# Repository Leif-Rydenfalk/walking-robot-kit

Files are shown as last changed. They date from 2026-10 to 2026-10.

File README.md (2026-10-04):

# Walking robot kit: electronics and control software

Open hardware and software for a small two-legged walking robot built on the
Arduino UNO Q. Fifteen Feetech bus servos on one TTL chain, a four-layer hat
that carries the camera, the audio, the distance sensor, the inertial sensor
and the servo bus, and a daemon on the board that owns the chain and serves a
live control page at 50 Hz.

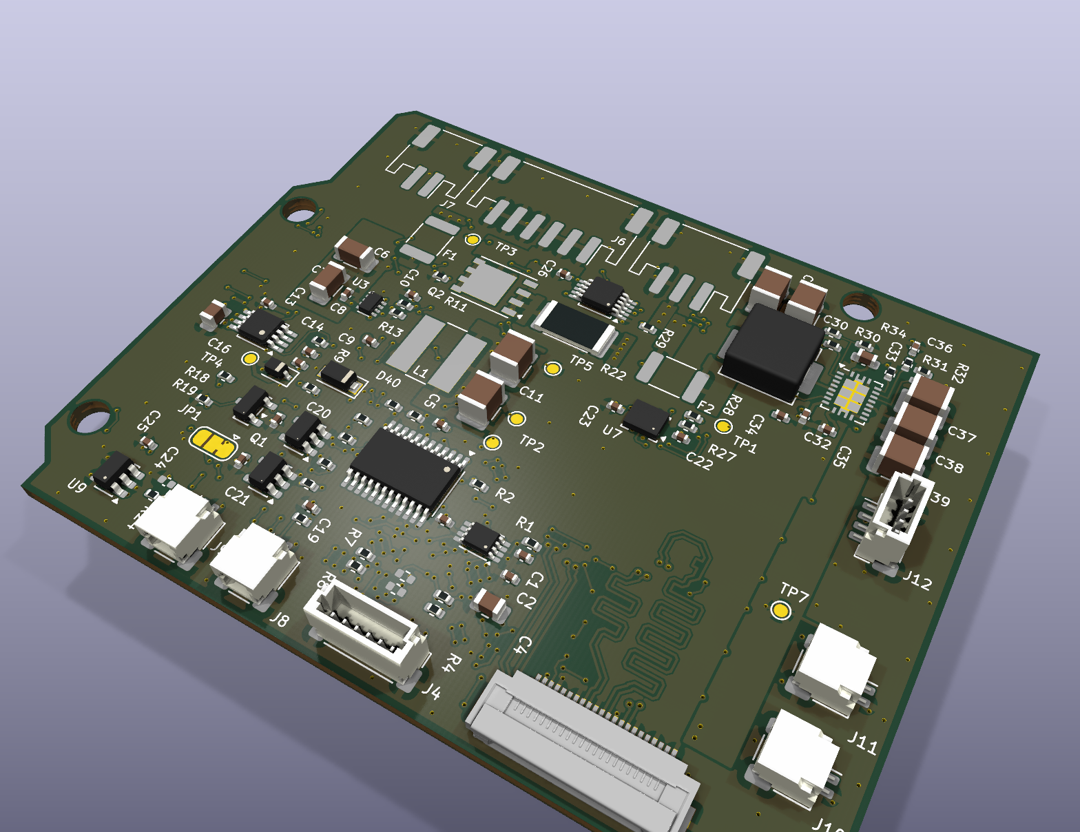
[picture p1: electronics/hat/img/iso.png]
the hat, top side


Everything here is ours and is yours to use. The printed shell is not in this
release yet; see [What is not here](#what-is-not-here).

## What is in the box

| folder | what |
|---|---|
| `electronics/hat/` | the UNO Q hat: KiCad project, schematic, gerbers, BOM and pick-and-place, plus the Python that generates all of it |
| `electronics/imu-board/` | a small breakout for the body inertial sensor |
| `firmware/bus-bridge/` | the Arduino sketch that runs the servo chain on the MCU |
| `software/servo-bus/` | the Rust daemon that owns the bus and serves the control page |
| `software/tools/` | small Python tools: check supply voltage, record joint limits, hold a pose |
| `docs/` | wiring, servo IDs, and how to bring the robot up the first time |

## What you need

- An Arduino UNO Q (ABX00162). The Linux side runs the daemon, the MCU side runs the bus.
- Fifteen Feetech STS-protocol bus servos at 1 Mbit/s. We use the HD-1910-C001.
- The hat from `electronics/hat/`, or a URT-2 adapter on D0/D1 if you only want to
  drive servos and skip the camera and audio.
- A battery between 5.0 V and 8.4 V with enough current for fifteen servos.
  Never a two-cell pack in series: 13 V burns every servo on the chain in seconds.
- A computer with Rust and either the board on your network or a USB cable.

## Build it

The hat is a four-layer board, 68.68 by 53.44 mm, ENIG. Send
`electronics/hat/fab/gerbers.zip` to any PCB maker, with `fab/bom.csv` and
`fab/cpl.csv` if you want it assembled. `electronics/hat/schematic.pdf` is the
circuit on paper. The KiCad 10 project is in `electronics/hat/kicad/` if you want
to change it, and `board.py`, `sch.py` and `hat_parts.py` are what generated it.

## Program it

Build the daemon for the board, on your computer:

    rustup target add aarch64-unknown-linux-gnu
    cargo install cargo-zigbuild                      # and install Zig
    cd software/servo-bus
    cargo zigbuild --release --target aarch64-unknown-linux-gnu

Then push the binary, the sketch and the service to the board:

    cd software
    BOARD=arduino@<board address> ./install.sh        # over the network
    ./install.sh --adb                                # or over USB

The sketch compiles and flashes on the board, which takes about a minute the
first time. Nothing moves: the daemon starts with torque untouched and only
reads the bus.

Try it without hardware first:

    cd software/servo-bus && cargo run --release -- --fake --port 8938

Then open <http://127.0.0.1:8938/>. The fake bus puts two servos on ID 1 so you
can see the duplicate-ID warning.

## Run it

Open `http://<board address>:8938/` on a phone or a computer. Every servo on the
chain shows up within two seconds: angle, load, current, temperature, supply
voltage, torque state and the angle limits it is clamped to. Add `?control` to
the URL for a position slider per servo.

Plug servos in one at a time to set their IDs. They all leave the factory at
ID 1. `docs/servos.md` has the ID map and what the page refuses to do.

`docs/running.md` is the first bring-up, in order: charge, power on, hold the
zero pose, check the inertial sensor, move one joint.

## What is not here

The printed shell. Our current parts were dimensioned from a third party's
simulation meshes, which are licensed for non-commercial use only, so we cannot
put them under an open licence. They are being redrawn from our own
measurements and will land here when that is done.

## Licence

The software, the firmware and the generator scripts are Apache-2.0
([LICENSE](LICENSE)). The board designs, the gerbers and the BOMs are
CC BY-SA 4.0 ([LICENSES/CC-BY-SA-4.0.txt](LICENSES/CC-BY-SA-4.0.txt)), because
the camera routing on the hat is copied from Arduino's own UNO Media Carrier,
which is share-alike.

Third-party work this builds on is credited in [NOTICE](NOTICE).

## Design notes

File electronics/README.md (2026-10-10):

# Electronics

Two boards. The hat is the one that matters; the IMU breakout is a small extra.

## hat

A four-layer hat for the Arduino UNO Q, 68.68 by 53.44 mm, 1.6 mm, ENIG. It
sits under the UNO Q on the two 2x30 board-to-board connectors and carries
everything the robot needs that the UNO Q does not have.

| block | part | notes |
|---|---|---|
| camera | 22-pin 0.5 mm flex connector on CSI0 | takes an IMX219 module. The ten CSI0 tracks are Arduino's own, copied from the UNO Media Carrier and length matched by them |
| power in | 6-pin JST PH pack plug (3 contacts per pole, 6 A), reverse-polarity FET, then two paths | 5.0 to 8.4 V in. Above that the daemon refuses to torque anything |
| UNO Q supply | TPS61088 boost to 11.86 V into the UNO Q's own VIN (7-24 V) | rev C. The hat never touches the UNO Q's 5 V or USB VBUS |
| amplifier supply | PTC, TPS62933 buck to 5 V | feeds only the amplifier |
| servo bus | half-duplex TTL with automatic direction | one 3-pin plug, the chain daisy-chains from there. Serial1, D0 and D1, 1 Mbit/s |
| pack monitor | INA226 across a 5 mOhm shunt in the pack feed | pack voltage and current |
| inertial | LSM6DSV16X on the 3.3 V bus at 0x6B | six axes with on-chip fusion |
| distance | header for a VL53L5CX or VL53L8CX breakout | |
| audio out | PAM8302A | one speaker plug |
| microphone | the carrier's microphone circuit | |
| touch | one capacitive pad | for petting the head |
| foot contacts | two 2-pin plugs | a switch or an FSR to ground per foot |

Everything except the board-to-board headers and the camera connector sits on
the bottom side, so nothing fouls the UNO Q above it.

### Getting one made

Send `hat/fab/gerbers.zip` to a PCB maker. Four layers, 1.6 mm, ENIG. Smallest
via is 0.20 mm drill on a 0.40 mm pad (one, inside the IMU's LGA); the rest are
0.25/0.45. For assembled boards add `fab/bom.csv`
and `fab/cpl.csv`; the part numbers are LCSC.
The order, with options, price and checks: `../docs/PCB-ORDER-LEIF-2026-10-11.md`.
Checks behind it: `hat/checks/` and `hat/docs/` (footprints, strap pins, power
budget, BOM stock).

`hat/schematic.pdf` is the circuit. `hat/kicad/` is the KiCad 10 project.

### Changing it

The board is generated, not drawn by hand. `hat_parts.py` is the whole design:
every part, every net, every position. `sch.py` turns it into the schematic and
`board.py` into the copper. Edit `hat_parts.py` and regenerate; do not edit the
KiCad files and expect the change to survive.

The CSI0 tracks are the exception. They are Arduino's, they are length matched,
and `board.py` locks them so the autorouter cannot touch them.

## imu-board

A two-layer breakout for an inertial sensor on the body plate, for when you
want the sensor away from the head. Same files, same process.

If you do not want to make a board for this, an MPU-6050 module wired straight
to the UNO Q header works. See `../docs/wiring.md`.

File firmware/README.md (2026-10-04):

# Firmware

One Arduino app, `bus-bridge`. It runs on the UNO Q's MCU and does one job:
own the servo chain on Serial1 and answer the Linux side over RouterBridge.

## What it does

- Drives the half-duplex TTL bus on D0 and D1 at 1 Mbit/s, with automatic
  direction. The hat handles the direction switch in hardware, so the sketch
  never has to toggle a transmit-enable pin.
- `bus_batch` is the fast path: one call carries a sync write of every goal
  position plus one telemetry read per servo, so a whole roster costs one
  round trip instead of fifteen.
- Sweeps the bus itself on a poll loop, so the Linux side reads a fresh
  snapshot rather than waiting for each servo in turn.
- Reads an MPU-6050 or compatible sensor over I2C, on whichever bus answers.
  It probes `Wire` (I2C2, the header pins) and `Wire1` (I2C4, the Qwiic
  socket) and reports which one replied. It does not assume.
- Drives the UNO Q's own 13 by 8 LED matrix, so the robot can show its state
  on its face.

## Flashing it

`../software/install.sh` copies this app to the board and starts it; the
sketch compiles and flashes there, which takes about a minute the first time.

By hand:

    adb push app.yaml    /home/arduino/ArduinoApps/servo-bus-mcu/app.yaml
    adb push sketch.ino  /home/arduino/ArduinoApps/servo-bus-mcu/sketch/sketch.ino
    adb push sketch.yaml /home/arduino/ArduinoApps/servo-bus-mcu/sketch/sketch.yaml
    adb push main.py     /home/arduino/ArduinoApps/servo-bus-mcu/python/main.py
    adb shell arduino-app-cli app start user:servo-bus-mcu

`main.py` is the Linux half of the app and does nothing but stay alive so the
app stays started. All the work is in `sketch.ino`.

## If the bus goes quiet

Hot-plugging a servo while the bus is running can wedge the MCU. The daemon on
the Linux side notices within a second and restarts this app, which takes about
twenty seconds, then carries on. You do not have to do anything.

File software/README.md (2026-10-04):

# Software

A Rust daemon that owns the servo bus, and a handful of Python tools that talk
to it.

## servo-bus

One process on the board's Linux side. It is the only thing allowed to touch
the bus, so nothing can fight it for the chain.

It has no dependencies. `Cargo.toml` has an empty `[dependencies]` on purpose:
the msgpack client, the HTTP server, the WebSocket and the JSON are all in
`src/`, because every one of them sits on the latency path.

### Build and install

    rustup target add aarch64-unknown-linux-gnu
    cargo install cargo-zigbuild        # and install Zig from ziglang.org
    cd servo-bus
    cargo zigbuild --release --target aarch64-unknown-linux-gnu

    cd ..
    BOARD=arduino@<board address> ./install.sh
    ./install.sh --adb                   # or over the USB cable

Then open `http://<board address>:8938/`.

### Without hardware

    cd servo-bus && cargo run --release -- --fake --port 8938

A fake bus with a few servos on it, including two sharing ID 1 so you can see
the duplicate warning. Tests run the same way: `cargo test`, no hardware.

### The page

| address | what |
|---|---|
| `/` | the roster: every servo's angle, load, current, temperature, supply voltage, torque state, limits and reply delay, updated 50 times a second. Set ID, torque off, duplicate-ID warning |
| `/?control` | the same, plus a position slider per servo |
| `/api/bus`, `/ws/bus` | the same data as JSON, polled or streamed every 20 ms |
| `/api/batch` | one call, many servos, for an outside controller |

Nothing moves unless you ask it to. The daemon starts with torque untouched,
and the page refuses to hold a servo whose ID is shared or which reads badly.

### How it keeps the servos safe

Every servo gets an angle band and goals outside it are refused, not clamped
silently. A servo with no recorded band cannot be driven at all; its slider
stays disabled. You record a band by turning the joint by hand end to end with
torque off, which the daemon watches, then saving it. The saved band is the
recorded ends minus three degrees each side, written to the servo's EEPROM and
read back.

A jaw that rests across twenty degrees and a hip that swings two hundred have
no business sharing one global limit. That is why the band is per servo.

### Speed

On an UNO Q, fifty roster updates a second. One update costs about 10.7 ms with
two servos; the link model puts sixteen servos at 16.7 ms. The limit is the
router-to-MCU link at 115200 baud, which costs about 5.5 ms per call plus 87 µs
per byte.

## tools

Small Python scripts that talk to the daemon over HTTP. No dependencies beyond
the standard library.

| tool | what |
|---|---|
| `bus_volts.py` | every servo's supply voltage and one verdict line. Safe is 5.0 to 8.4 V |
| `record_limits.py` | walk one joint end to end and save the band |
| `limits_table.py` | the bands as a table |
| `pose.py` | hold the robot in a pose by hand, record it, then have it go there by itself |
| `zero_now.py` | read the current pose and treat it as zero |
| `fte.py` | the shared client the others use: Feetech packets through the daemon's raw door |

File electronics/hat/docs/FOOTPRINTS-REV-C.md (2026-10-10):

# Rev C footprints against their datasheets

foreman/microduck-assembly.60, 2026-10-10. Generated by `tools/fp_table.py` from `data/fp-geometry.json` (pads read from the built `kicad/unoq_hat.kicad_pcb`) and `data/bom-stock.json`. Datasheets: `kit/ref/ds/<LCSC>.pdf`.

Pin 1 = pad "1" position in footprint coordinates (mm). Pitch = smallest pad centre spacing. Pin-to-net mapping is checked separately by `sch check` (74/74 nets agree between schematic and board, `checks/build-summary.json`).

| refs | LCSC | MPN | footprint | pads | pin 1 (mm) | pitch | pad w x h | datasheet vs board | verdict | datasheet |
|---|---|---|---|---|---|---|---|---|---|---|
| J1, J2 | C191721 | 1.27-2*30P | UNOQ_JMEDIA_2x30_P1.27_Male | 60 | (-18.415, -2.135) | 1.27 | 0.7x2.57 | Arduino UNO Q carrier JMEDIA/JMISC land (GPEC212-3002A011C1AF) from the Arduino carrier files: 0.7x2.57 pads, 1.27 pitch, rows 4.27 apart; 142 carrier lands matched in validation/2026-10-07-v1. Part is a BOOMELE equivalent, not the Greenconn original: first boards are the fit test | PASS, fit test | [pdf](https://datasheet.lcsc.com/datasheet/pdf/3aedae07ef21d25ca8d950ab4b2f9895.pdf?productCode=C191721) |
| R1, R2, R7, R8, R15, R16, R17, R18, R29, R25, R26 | C25744 | 0402WGF1002TCE | R_0402_1005Metric | 2 | (-0.51, 0) | 1.02 | 0.54x0.64 | IPC-7351 nominal KiCad library land; JLC basic part, same land on every 0402/0603/0805/1206/1210 the house places | PASS | [pdf](https://datasheet.lcsc.com/datasheet/pdf/0a975aaa49b7c97f38a963127be4a823.pdf?productCode=C25744) |
| R3, R4 | C17168 | 0402WGF0000TCE | R_0402_1005Metric | 2 | (-0.51, 0) | 1.02 | 0.54x0.64 | IPC-7351 nominal KiCad library land; JLC basic part, same land on every 0402/0603/0805/1206/1210 the house places | PASS | [pdf](https://datasheet.lcsc.com/datasheet/pdf/0a975aaa49b7c97f38a963127be4a823.pdf?productCode=C17168) |
| C2, C3, C5, C19, C20, C21, C13, C14, C15, C22, C23, C26, C25 | C1525 | CL05B104KO5NNNC | C_0402_1005Metric | 2 | (-0.48, 0) | 0.96 | 0.56x0.62 | IPC-7351 nominal KiCad library land; JLC basic part, same land on every 0402/0603/0805/1206/1210 the house places | PASS | [pdf](https://datasheet.lcsc.com/datasheet/pdf/02336ea48ea44ca18c72517dd3cb7b47.pdf?productCode=C1525) |
| F1 | C702820 | SMD1812P300TF/16 | Fuse_1812_4532Metric | 2 | (-2.138, 0) | 4.276 | 1.125x3.4 | 1812 PTC: Ruilon pad layout F 1.78 / G 3.45 / H 3.15. Board KiCad Fuse_1812 1.125x3.4 at +-2.138 (gap 3.15, overall 5.4): same gap, narrower pads, fine for a 4.5 mm body | PASS | [pdf](https://datasheet.lcsc.com/datasheet/pdf/cfa74b12b2251ef3c7fa909bdad1e8a9.pdf?productCode=C702820) |
| C33 | C19666 | CL10A475KO8NNNC | C_0603_1608Metric | 2 | (-0.775, 0) | 1.55 | 0.9x0.95 | IPC-7351 nominal KiCad library land; JLC basic part, same land on every 0402/0603/0805/1206/1210 the house places | PASS | [pdf](https://datasheet.lcsc.com/datasheet/pdf/02336ea48ea44ca18c72517dd3cb7b47.pdf?productCode=C19666) |
| C11, C12, C30, C31, C37, C38, C39 | C52306 | CL32A226KAJNNNE | C_1210_3225Metric | 2 | (-1.475, 0) | 2.95 | 1.15x2.7 | IPC-7351 nominal KiCad library land; JLC basic part, same land on every 0402/0603/0805/1206/1210 the house places | PASS | [pdf](https://datasheet.lcsc.com/datasheet/pdf/02336ea48ea44ca18c72517dd3cb7b47.pdf?productCode=C52306) |
| J7 | C295747 | S2B-PH-SM4-TB(LF)(SN) | JST_PH_S2B-PH-SM4-TB_1x02-1MP_P2.00mm_Horizontal | 2 | (-1, 2.85) | 2 | 1x3.5, 1.5x3.4 | JST PH S2B-PH-SM4-TB, same family as J6 | PASS | [pdf](https://datasheet.lcsc.com/datasheet/pdf/2474e9261ed7c5f86b55d373e724589d.pdf?productCode=C295747) |
| C1 | C23733 | CL05A475MP5NRNC | C_0402_1005Metric | 2 | (-0.48, 0) | 0.96 | 0.56x0.62 | IPC-7351 nominal KiCad library land; JLC basic part, same land on every 0402/0603/0805/1206/1210 the house places | PASS | [pdf](https://datasheet.lcsc.com/datasheet/pdf/02336ea48ea44ca18c72517dd3cb7b47.pdf?productCode=C23733) |
| R21, R24 | C106235 | RC0402FR-071KL | R_0402_1005Metric | 2 | (-0.51, 0) | 1.02 | 0.54x0.64 | IPC-7351 nominal KiCad library land; JLC basic part, same land on every 0402/0603/0805/1206/1210 the house places | PASS | [pdf](https://datasheet.lcsc.com/datasheet/pdf/b426be3ce22c6de3e0c3a2248e49159e.pdf?productCode=C106235) |
| C6, C7 | C77090 | GRM31CR61E106KA12L | C_1206_3216Metric | 2 | (-1.475, 0) | 2.95 | 1.15x1.8 | IPC-7351 nominal KiCad library land; JLC basic part, same land on every 0402/0603/0805/1206/1210 the house places | PASS | [pdf](https://datasheet.lcsc.com/datasheet/pdf/5d6d0805a03309170176423d23331af1.pdf?productCode=C77090) |
| L2 | C167218 | FXL0630-2R2-M | L_Changjiang_FXL0630 | 2 | (-3.025, 0) | 6.05 | 2.35x3.5 | FXL0630 land: a 3.7 gap, b 8.4 overall, c 3.5. Board 2.35x3.5 at +-3.025 (gap 3.7, overall 8.4) | PASS | [pdf](https://datasheet.lcsc.com/datasheet/pdf/40dfb6cb4606b2ccaa4e89438a42f563.pdf?productCode=C167218) |
| U7 | C5267406 | LSM6DSV16XTR | LGA-14_3x2.5mm_P0.5mm_LayoutBorder3x4y | 14 | (-1.163, 0.75) | 0.5 | 0.35x0.625, 0.625x0.35 | ST LSM6DSV16X LGA-14 2.5x3, 0.5 pitch; ST TN0018 land: pad = package pad +0.1 outward. Board 0.625x0.35 (package 0.475x0.25) | PASS | [pdf](https://datasheet.lcsc.com/datasheet/pdf/7d66556bb254f99e058243c7371e051d.pdf?productCode=C5267406) |
| U3 | C3200405 | TPS62933DRLR | SOT-583-8 | 8 | (-0.74, 0.75) | 0.5 | 0.67x0.3 | TI DRL0008A land: 0.67x0.3, 0.5 pitch, row 1.48. Board identical | PASS | [pdf](https://datasheet.lcsc.com/datasheet/pdf/8822d9443d3405e5b17304ebbb56ac2c.pdf?productCode=C3200405) |
| J3 | C3169786 | TF31-22S-0.5SH(800) | FFC_22P_P0.5_TF31-22S | 23 | (5.25, 1.625) | 0.5 | 0.3x1.3, 1.8x2.2 | TF31-22S land table: A 10.5 (21x0.5 pitch), B 12.5, C 16.3. Board: pins +-5.25 = 10.5, shield pads inner 12.5, outer 16.1 (0.1/side short). Signal 0.3x1.3 | PASS | [pdf](https://datasheet.lcsc.com/datasheet/pdf/1f4b27665a7c1a8cc6f29d17b6cec7db.pdf?productCode=C3169786) |
| J4 | C160392 | BM06B-SRSS-TB(LF)(SN) | JST_SH_BM06B-SRSS-TB_1x06-1MP_P1.00mm_Vertical | 6 | (-2.5, -1.325) | 1 | 0.6x1.55, 1.2x1.8 | JST SH BM06B-SRSS-TB: 0.6x1.55, 1.2x1.8, 1.0 pitch | PASS | [pdf](https://datasheet.lcsc.com/datasheet/pdf/e03a82bcc66e3c3589917313e54d45e2.pdf?productCode=C160392) |
| U10 | C87357 | TPS61088RHLR | Texas_VQFN-RHL-20 | 21 | (-0.75, 2.15) | 0.475 | 0.2x0.6, 0.24x0.6, 0.6x0.24 | TI RHL0020A (VQFN 3.5x4.5, 0.5 pitch, 20 pins + EP): KiCad Texas_VQFN-RHL-20 (no thermal-via variant; 4 EP vias placed by board.py in the J1 row channel). Pin map read against datasheet p3 (SW 2-4, VIN 5, PGND 11/12/20, FB 17, COMP 18, ILIM 19, FSW 3/VCC 6...) | PASS | [pdf](https://datasheet.lcsc.com/datasheet/pdf/7466a2af04454f0896e70eb827692387.pdf?productCode=C87357) |
| J8, J9, J10, J11 | C160402 | SM02B-SRSS-TB(LF)(SN) | JST_SH_SM02B-SRSS-TB_1x02-1MP_P1.00mm_Horizontal | 2 | (-0.5, 2) | 1 | 0.6x1.55, 1.2x1.8 | JST SH SM02B-SRSS-TB: 0.6x1.55, 1.2x1.8, 1.0 pitch | PASS | [pdf](https://datasheet.lcsc.com/datasheet/pdf/40c649e22fa9bda892cfec952005fd51.pdf?productCode=C160402) |
| C4, C16 | C1713 | CL21A106KOQNNNE | C_0805_2012Metric | 2 | (-0.95, 0) | 1.9 | 1x1.45 | IPC-7351 nominal KiCad library land; JLC basic part, same land on every 0402/0603/0805/1206/1210 the house places | PASS | [pdf](https://datasheet.lcsc.com/datasheet/pdf/02336ea48ea44ca18c72517dd3cb7b47.pdf?productCode=C1713) |
| C36 | C1542 | 0402B682K500NT | C_0402_1005Metric | 2 | (-0.48, 0) | 0.96 | 0.56x0.62 | IPC-7351 nominal KiCad library land; JLC basic part, same land on every 0402/0603/0805/1206/1210 the house places | PASS | [pdf](https://datasheet.lcsc.com/datasheet/pdf/09fe2daf22580a99fa7fea93ccb20fb7.pdf?productCode=C1542) |
| C8, C9, C32, C34 | C105883 | CC0402KRX7R8BB104 | C_0402_1005Metric | 2 | (-0.48, 0) | 0.96 | 0.56x0.62 | IPC-7351 nominal KiCad library land; JLC basic part, same land on every 0402/0603/0805/1206/1210 the house places | PASS | [pdf](https://datasheet.lcsc.com/datasheet/pdf/23ccee80ee542e7cf156a772bb589942.pdf?productCode=C105883) |
| R27, R28 | C25900 | 0402WGF4701TCE | R_0402_1005Metric | 2 | (-0.51, 0) | 1.02 | 0.54x0.64 | IPC-7351 nominal KiCad library land; JLC basic part, same land on every 0402/0603/0805/1206/1210 the house places | PASS | [pdf](https://datasheet.lcsc.com/datasheet/pdf/0a975aaa49b7c97f38a963127be4a823.pdf?productCode=C25900) |
| C10 | C60133 | CC0402KRX7R9BB103 | C_0402_1005Metric | 2 | (-0.48, 0) | 0.96 | 0.56x0.62 | IPC-7351 nominal KiCad library land; JLC basic part, same land on every 0402/0603/0805/1206/1210 the house places | PASS | [pdf](https://datasheet.lcsc.com/datasheet/pdf/23ccee80ee542e7cf156a772bb589942.pdf?productCode=C60133) |
| U2 | C465732 | TCA9555PWR | TSSOP-24_4.4x7.8mm_P0.65mm | 24 | (-2.862, 3.575) | 0.65 | 1.475x0.4 | TI PW0024A land: 1.5x0.45, 0.65 pitch, row 5.8. Board 1.475x0.4, span 5.724 | PASS | [pdf](https://datasheet.lcsc.com/datasheet/pdf/b87b1e8b19259fa8f353ae4a0dd9a62d.pdf?productCode=C465732) |
| D1 | C151348 | BZT52C5V1S-7-F | D_SOD-323 | 2 | (-1.05, 0) | 2.1 | 0.6x0.45 | SOD-323 land: X 0.59, X1 2.7, Y 0.45. Board 0.6x0.45 pitch 2.1 (overall 2.7) | PASS | [pdf](https://datasheet.lcsc.com/datasheet/pdf/e91584fb3d2d85e136baa2628fef5f07.pdf?productCode=C151348) |
| D40 | C426769 | BAT54H,115 | BAT54H_Nexperia_SOD123F | 2 | (-1.4, 0) | 2.8 | 1.2x1.2 | Nexperia SOD123F reflow footprint: lands 1.2 long, outer 4.0, inner 1.6, 1.1 wide. Board custom 1.2x1.2 at pitch 2.8 (outer 4.0, inner 1.6) | PASS | [pdf](https://datasheet.lcsc.com/datasheet/pdf/5d452729b69b0536541be9ab4ef736d3.pdf?productCode=C426769) |
| U1 | C840107 | TCA9406DCUR | VSSOP-8_2.3x2mm_P0.5mm | 8 | (-1.4, 0.75) | 0.5 | 1.25x0.35 | TI DCU0008A land: 0.85x0.3 pads, 0.5 pitch, row 3.1. Board 1.25x0.35, span 2.8 (KiCad VSSOP-8 2.3x2): pads reach the same toe, 0.05 wider. Pin 1 top-left | PASS | [pdf](https://www.ti.com/cn/lit/ds/symlink/tca9406.pdf) |
| U9 | C2890349 | TTP233H-BA6 | SOT-23-6 | 6 | (-1.137, 0.95) | 0.95 | 1.325x0.6 | TTP233H-BA6 SOT-23-6L: KiCad SOT-23-6 1.325x0.6, 0.95 pitch. Pin 1 = Q, 3 = I (touch), pin map in hat_parts.py | PASS | [pdf](https://datasheet.lcsc.com/datasheet/pdf/6f5612c685ffeaea62cc8564d21239f1.pdf?productCode=C2890349) |
| R32 | C26083 | 0402WGF1004TCE | R_0402_1005Metric | 2 | (-0.51, 0) | 1.02 | 0.54x0.64 | IPC-7351 nominal KiCad library land; JLC basic part, same land on every 0402/0603/0805/1206/1210 the house places | PASS | [pdf](https://datasheet.lcsc.com/datasheet/pdf/0a975aaa49b7c97f38a963127be4a823.pdf?productCode=C26083) |
| Q2 | C13899 | AON6407 | PowerPAK_SO-8_Single | 5 | (-2.67, 1.905) | 1.27 | 1.02x0.61, 1.27x0.61, 3.81x3.91 | AON6407 DFN5x6: PowerPAK SO-8 single land (pins 1-3 S, 4 G, 5-8+tab D), 1.27 pitch, 3.81x3.91 tab. Datasheet land is image-only; pinout S/S/S/G matches | PASS | [pdf](https://datasheet.lcsc.com/datasheet/pdf/0934e1c0e13d4ba28c7432f63cfc1997.pdf?productCode=C13899) |
| R11, R13, R9, R35, R36 | C25741 | 0402WGF1003TCE | R_0402_1005Metric | 2 | (-0.51, 0) | 1.02 | 0.54x0.64 | IPC-7351 nominal KiCad library land; JLC basic part, same land on every 0402/0603/0805/1206/1210 the house places | PASS | [pdf](https://datasheet.lcsc.com/datasheet/pdf/0a975aaa49b7c97f38a963127be4a823.pdf?productCode=C25741) |
| U5 | C7834 | SN74LVC1G126DBVR | SOT-23-5 | 5 | (-1.137, 0.95) | 0.95 | 1.325x0.6 | TI DBV0005A land: 1.1x0.6 pads, 0.95 pitch, row 2.6. Board SOT-23-5 1.325x0.6, span 2.275 centres. Pin 1 bottom-left | PASS | [pdf](https://datasheet.lcsc.com/datasheet/pdf/3d79861610d54464b4b035cabb370158.pdf?productCode=C7834) |
| R33 | C25746 | 0402WGF1133TCE | R_0402_1005Metric | 2 | (-0.51, 0) | 1.02 | 0.54x0.64 | IPC-7351 nominal KiCad library land; JLC basic part, same land on every 0402/0603/0805/1206/1210 the house places | PASS | [pdf](https://datasheet.lcsc.com/datasheet/pdf/0a975aaa49b7c97f38a963127be4a823.pdf?productCode=C25746) |
| J6 | C265405 | S6B-PH-SM4-TB(LF)(SN) | JST_PH_S6B-PH-SM4-TB_1x06-1MP_P2.00mm_Horizontal | 6 | (-5, 2.85) | 2 | 1x3.5, 1.5x3.4 | JST PH S6B-PH-SM4-TB (pack in, 3 contacts per pole): 1.0x3.5 signal, 1.5x3.4 mount, 2.0 pitch, pins +-5.0, mount pads +-7.35 (JST drawing; KiCad footprint drawn from it) | PASS | [pdf](https://datasheet.lcsc.com/datasheet/pdf/fd6b0599884a99953f02d32fdcec9311.pdf?productCode=C265405) |
| U8 | C49851 | INA226AIDGSR | TSSOP-10_3x3mm_P0.5mm | 10 | (-2.15, 1) | 0.5 | 1.45x0.3 | TI DGS0010A land: 1.45x0.3, 0.5 pitch, row 4.4. Board 1.45x0.3, span 4.3 | PASS | [pdf](https://datasheet.lcsc.com/datasheet/pdf/c67b965eb2a01e8d671b6f15d639e314.pdf?productCode=C49851) |
| J12 | C160390 | BM04B-SRSS-TB(LF)(SN) | JST_SH_BM04B-SRSS-TB_1x04-1MP_P1.00mm_Vertical | 4 | (-1.5, -1.325) | 1 | 0.6x1.55, 1.2x1.8 | JST SH BM04B-SRSS-TB: 0.6x1.55 signal, 1.2x1.8 mount, 1.0 pitch | PASS | [pdf](https://datasheet.lcsc.com/datasheet/pdf/00659630c8ad1e2184fc3218d8262faf.pdf?productCode=C160390) |
| F2 | C2844238 | JK-MSMD500L-12V | Fuse_1812_4532Metric | 2 | (-2.138, 0) | 4.276 | 1.125x3.4 | JK-MSMD500L 1812 PTC: same 1812 body (4.37-4.73 x 3.07-3.41) as F1; same land | PASS | [pdf](https://datasheet.lcsc.com/datasheet/pdf/4b6c851584ad23fd00938c1a71f72301.pdf?productCode=C2844238) |
| R14 | C25879 | 0402WGF2201TCE | R_0402_1005Metric | 2 | (-0.51, 0) | 1.02 | 0.54x0.64 | IPC-7351 nominal KiCad library land; JLC basic part, same land on every 0402/0603/0805/1206/1210 the house places | PASS | [pdf](https://datasheet.lcsc.com/datasheet/pdf/0a975aaa49b7c97f38a963127be4a823.pdf?productCode=C25879) |
| R22 | C185817 | RLM25FEER005 | R_2512_6332Metric | 2 | (-2.962, 0) | 5.924 | 1.225x3.35 | RLM25 2512 shunt land: a 4.0, b 2.1, L 4.1 for 0.004-0.050 ohm. Board KiCad R_2512 1.225x3.35 at pitch 5.924. Kelvin taps in board.py | PASS | [pdf](https://datasheet.lcsc.com/datasheet/pdf/f42cc89de166d1a84d9a917c44512826.pdf?productCode=C185817) |
| Q1 | C727128 | MMBT3906 | SOT-23 | 3 | (-0.938, 0.95) | 1.9 | 1.475x0.6 | SOT-23 (TO-236AB): KiCad SOT-23 1.475x0.6, pins 1/2 west, 3 east | PASS | [pdf](https://datasheet.lcsc.com/datasheet/pdf/5fb8abfb58de49a9e93c5a14c4951afe.pdf?productCode=C727128) |
| R19 | C25765 | 0402WGF2002TCE | R_0402_1005Metric | 2 | (-0.51, 0) | 1.02 | 0.54x0.64 | IPC-7351 nominal KiCad library land; JLC basic part, same land on every 0402/0603/0805/1206/1210 the house places | PASS | [pdf](https://datasheet.lcsc.com/datasheet/pdf/0a975aaa49b7c97f38a963127be4a823.pdf?productCode=C25765) |
| R30 | C25774 | 0402WGF3003TCE | R_0402_1005Metric | 2 | (-0.51, 0) | 1.02 | 0.54x0.64 | IPC-7351 nominal KiCad library land; JLC basic part, same land on every 0402/0603/0805/1206/1210 the house places | PASS | [pdf](https://datasheet.lcsc.com/datasheet/pdf/0a975aaa49b7c97f38a963127be4a823.pdf?productCode=C25774) |
| R31 | C25755 | 0402WGF1503TCE | R_0402_1005Metric | 2 | (-0.51, 0) | 1.02 | 0.54x0.64 | IPC-7351 nominal KiCad library land; JLC basic part, same land on every 0402/0603/0805/1206/1210 the house places | PASS | [pdf](https://datasheet.lcsc.com/datasheet/pdf/0a975aaa49b7c97f38a963127be4a823.pdf?productCode=C25755) |
| R12 | C27011 | 0402WGF5233TCE | R_0402_1005Metric | 2 | (-0.51, 0) | 1.02 | 0.54x0.64 | IPC-7351 nominal KiCad library land; JLC basic part, same land on every 0402/0603/0805/1206/1210 the house places | PASS | [pdf](https://datasheet.lcsc.com/datasheet/pdf/0a975aaa49b7c97f38a963127be4a823.pdf?productCode=C27011) |
| U4 | C113367 | PAM8302AASCR | MSOP-8_3x3mm_P0.65mm | 8 | (-2.112, 0.975) | 0.65 | 1.625x0.4 | PAM8302 MSOP-8: C 0.65, X 0.45, Y 1.35, Y1 5.3. Board 1.625x0.4, span 4.224 (toe 5.85): longer, 0.05 narrower | PASS | [pdf](https://datasheet.lcsc.com/datasheet/pdf/f2301bec36461d1ce751d45a4a680a5d.pdf?productCode=C113367) |
| U6 | C23654 | SN74LVC1G125DBVR | SOT-23-5 | 5 | (-1.137, 0.95) | 0.95 | 1.325x0.6 | Same DBV0005A as U5 | PASS | [pdf](https://datasheet.lcsc.com/datasheet/pdf/397db609d8c243daaad8f1a233af4e5d.pdf?productCode=C23654) |
| L1 | C168072 | FNR6045S6R8MT | FNR6045_6.0x6.0mm | 2 | (-2.15, 0) | 4.3 | 2.1x6.2 | FNR6045 6x6 shielded inductor: land carried from Rev B validation (2.1x6.2 at +-2.15); datasheet text is image-only | PASS (Rev B land) | [pdf](https://datasheet.lcsc.com/datasheet/pdf/a0b12ba9dfe6b9e66b6bb852b7c71c03.pdf?productCode=C168072) |
| J5 | C265101 | S3B-PH-SM4-TB(LF)(SN) | JST_PH_S3B-PH-SM4-TB_1x03-1MP_P2.00mm_Horizontal | 3 | (-2, 2.85) | 2 | 1x3.5, 1.5x3.4 | JST PH S3B-PH-SM4-TB, same family as J6 | PASS | [pdf](https://datasheet.lcsc.com/datasheet/pdf/6c6fce4367275d84ec6a99bf09f1250f.pdf?productCode=C265101) |
| R34 | C25762 | 0402WGF1802TCE | R_0402_1005Metric | 2 | (-0.51, 0) | 1.02 | 0.54x0.64 | IPC-7351 nominal KiCad library land; JLC basic part, same land on every 0402/0603/0805/1206/1210 the house places | PASS | [pdf](https://datasheet.lcsc.com/datasheet/pdf/0a975aaa49b7c97f38a963127be4a823.pdf?productCode=C25762) |
| C35 | C82219 | 0402B473K500NT | C_0402_1005Metric | 2 | (-0.48, 0) | 0.96 | 0.56x0.62 | IPC-7351 nominal KiCad library land; JLC basic part, same land on every 0402/0603/0805/1206/1210 the house places | PASS | [pdf](https://datasheet.lcsc.com/datasheet/pdf/09fe2daf22580a99fa7fea93ccb20fb7.pdf?productCode=C82219) |
| R20 | C138002 | RC0402FR-0733RL | R_0402_1005Metric | 2 | (-0.51, 0) | 1.02 | 0.54x0.64 | IPC-7351 nominal KiCad library land; JLC basic part, same land on every 0402/0603/0805/1206/1210 the house places | PASS | [pdf](https://datasheet.lcsc.com/datasheet/pdf/b426be3ce22c6de3e0c3a2248e49159e.pdf?productCode=C138002) |

51 footprints, 0 not PASS.

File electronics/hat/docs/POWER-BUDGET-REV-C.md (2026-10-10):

# Rev C power budget

foreman/microduck-assembly.60, 2026-10-10. Every rail on the UNO Q head hat, its
source, its limit, the worst load we can name, and the margin. Margin = 1 - load/limit.

## 1. The power tree

```
2S pack 5.0-8.4 V ── J6 (JST PH 6-pin, 3 contacts per pole) ── Q2 AON6407 reverse-polarity P-FET
   └─ R22 5 mOhm shunt (INA226 U8 reads V and I) ── VBAT
        ├─ F2 5 A PTC ── U10 TPS61088 boost ── VIN12 11.86 V ── J1.57 + J1.59 ── UNO Q VIN
        │                                                         (UNO Q makes its own 5 V, 3.3 V, 1.8 V)
        ├─ F1 3 A PTC ── U3 TPS62933 buck ── V5 5.0 V ── U4 PAM8302 amplifier only
        └─ J5.2 servo-bus VBAT reference (see section 4)
UNO Q +3V3 (J1.58/60, J2.53/55) and +1V8 (J2.57) ── hat logic, camera, ToF, IMU
```

Rev C change: the hat no longer back-feeds the UNO Q's 5 V (JMISC 54/56 are open). The
UNO Q runs from its own VIN, fed by the boost. V5 now feeds only the amplifier.

## 2. Loads

| load | rail | worst current | source of the number |
|---|---|---|---|
| UNO Q, whole board | VIN12 | 15 W on 5V_SYS (3 A) | ABX00162 datasheet sec. 3.1, 5V_SYS max |
| UNO Q VIN path | VIN12 | 15 W / 0.90 buck + Schottky 0.39 V drop = 18.1 W = 1.52 A at 11.86 V | UNO Q schematic: VIN buck then Schottky; 90 % buck assumed |
| camera module (IMX219 class) | UNO Q +3V3 / +1V8 | 250 mA | `board.py` RAIL netclass note |
| VL53L5CX ToF (J4) | +3V3 | 100 mA | same |
| LSM6DSV16X, TCA9555, INA226, TCA9406, TTP233H, buffers | +3V3 | < 10 mA together | datasheets (each under 1 mA active) |
| PAM8302 at 2.5 W into 4 ohm | V5 | 0.65 A peak | PAM8302 datasheet, 2.5 W at 5 V |
| U10 EN divider R35+R36 | VBAT_B | 42 uA at 8.4 V | Ohm's law |

The hat's 3.3 V and 1.8 V loads come out of the UNO Q's own regulators, so they are
inside the UNO Q's 15 W above and do not add to the hat converters.

## 3. Margin per rail

| rail / part | limit | worst load | margin | notes |
|---|---|---|---|---|
| VIN12 boost output (U10) | 2.03 A at 5.0 V in | 1.52 A | **25 %** | limit from ILIM min 7.1 A (R31 150k), ripple 3.4 A p-p with L -20 %, 90 % efficiency. At 6.0 V pack the limit is 2.43 A (37 %) |
| L2 FXL0630-2R2 | Isat 10.5 A | 5.4 A peak | **49 %** | peak = average input 4.0 A + half ripple 1.4 A (nominal L) |
| L2 inside current limit | ILIM min 7.1 A | 5.4 A peak | **24 %** | the boost limits before L2 saturates |
| F2 JK-MSMD500L (VBAT_B) | 5.0 A hold at 25 C | 4.0 A at 5.0 V pack | **20 %** | at 6.0 V pack 3.34 A (33 %). PTC hold falls about 20 % at 50 C: at a hot, empty pack the margin is near zero, see 5.1 |
| JMEDIA J1.57 + J1.59 (UNO Q VIN) | 1.0 A per contact | 0.76 A each | **24 %** | two contacts share 1.52 A |
| U10 junction | 125 C | 102 C at 40 C ambient | **18 %** | about 1.6 W in the IC (2.0 W total loss at 90 %, 0.24 W of it in L2) at worst load x RthJA 38.8 C/W |
| V5 buck (U3 TPS62933) | 3 A | 0.65 A | **78 %** | amplifier only after Rev C |
| F1 SMD1812P300TF (VBAT_F) | 3.0 A hold | 0.72 A at 5.0 V pack | **76 %** | |
| L1 FNR6045 6.8 uH | 3.3 A | 0.65 A + ripple | **> 70 %** | |
| R22 shunt 2 W | 2 W | 4.7 A: 0.11 W | **95 %** | INA226 range +-81.92 mV = +-16 A |
| Q2 AON6407 | 85 A class, < 6 mOhm | 4.7 A: 0.13 W | **> 90 %** | |
| J6 pack connector S6B-PH-SM4-TB, 3 contacts per pole | 6 A (2 A per JST PH contact) | 4.72 A at 5.0 V with UNO Q at 15 W and amp at full | **21 %** | realistic load 2.76 A (54 %). Was 2 per pole (4 A, -18 %) until build #10 |
| UNO Q +3V3 to hat | UNO Q regulator (inside 15 W) | 360 mA | - | the hat adds no regulator here |

## 4. Servo power

Servo power does not come from this board (`docs/wiring.md`: give the chain its own
5.0-8.4 V supply and share ground). J5 pin 2 carries VBAT only as a reference for a
servo bus that is powered elsewhere. A JST PH contact is rated 2 A; do not run servo
current through J5.

## 5. Corners to know

### 5.1 Hot, empty pack

At 5.0 V in, 50 C board and the UNO Q at its 15 W maximum, F2's hold current (about 4 A
derated) meets the 4.0 A draw. The UNO Q never draws 15 W from 5V_SYS in this robot:
that figure includes the USB-C host port at 3 A. A realistic heavy load (NPU plus camera
streaming, 8 W) needs 2.04 A from the pack at 5.0 V, 49 % under F2's derated hold.

### 5.2 J6 pack connector

Up to build #9 J6 was a 4-pin PH with two contacts per pole: 4 A, below the 4.72 A worst
case (UNO Q at 15 W plus the amplifier at full, 5.0 V pack). A kit buyer plugs in whatever
they have, so build #10 (2026-10-10) made J6 a 6-pin S6B-PH-SM4-TB (C265405) with three
contacts per pole: 6 A, 21 % over the worst case. The kit ships a J6-to-XT30 pigtail so the
buyer plugs in a normal 2S pack (see the order sheet).

## 6. Method

- Boost limit: D = 1 - VIN x eta / VOUT; ripple = VIN x D / (L x fSW); average input
  limit = ILIM min - ripple/2; IOUT = Iin x VIN x eta / VOUT. ILIM min from the datasheet
  spread at 100k (10.6/11.9) applied to 7.93 A typ.
- fSW from datasheet equation 2 with R30 = 300k (516 kHz at 5.0 V in).
- Strap pins and compensation: `STRAP-PINS-REV-C.md`.

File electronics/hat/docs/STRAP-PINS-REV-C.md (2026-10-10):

# Rev C strap pins against their datasheets

foreman/microduck-assembly.60, 2026-10-10. One row per configuration pin (enable,
undervoltage, mode, boot, address, frequency, limit, compensation, unused inputs) on
every IC of the Rev C hat. Net names are from `hat_parts.py` NETS; datasheets are
`kit/ref/ds/<LCSC>.pdf` (URLs in `data/bom-stock.json`).

DRC and ERC cannot see these: a pin wired to the wrong rail is still a legal net.
This pass found one real fault (row 1), fixed in build #8.

## Result

| # | IC | pin | net / part | datasheet says | board | verdict |
|---|---|---|---|---|---|---|
| 1 | U10 TPS61088 | 2 EN | BST_EN: R35 100k to VBAT_B, R36 100k to GND | EN high enables, low = shutdown (VENH 1.2 V, VENL 0.4 V); abs max EN 7 V; VCC (pin 1) is the internal LDO output and the LDO sits under shutdown control (block diagram; ISD 1 uA) | Rev C up to build #7 tied EN to VCC: VCC is 0 V in shutdown, so the boost never starts and the UNO Q gets no VIN. Build #8: 1:1 divider, EN = 2.5 V at 5.0 V pack, 4.2 V at 8.4 V; 42 uA | **FIXED** (was FAIL) |
| 2 | U10 | 1 VCC | C33 4.7 uF 0603 to GND | ceramic > 1.0 uF required | 4.7 uF 16 V X5R (about 2.5 uF at 5.2 V bias) | PASS |
| 3 | U10 | 3 FSW | R30 300k to SW2 | RFREQ = 4(1/fSW - tDELAY*VOUT/VIN)/CFREQ, CFREQ 23 pF, tDELAY 89 ns; must always be fitted | 516 kHz at 5.0 V in, 540 kHz at 8.4 V; 200 kHz-2.2 MHz range | PASS |
| 4 | U10 | 8 BOOT | C34 100 nF to SW2 | 0.1 uF BOOT-SW (typical application) | 100 nF 25 V | PASS |
| 5 | U10 | 10 SS | C35 47 nF to GND | 5 uA charge to 1.204 V; "47 nF is usually sufficient" | tSS = 47n x 1.204 / 5u = 11 ms | PASS |
| 6 | U10 | 11, 12 NC | GND | "connect these two pins to ground plane for thermal dissipation" | GND, stubs to EP | PASS |
| 7 | U10 | 13 MODE | not connected | floating = PFM at light load, GND = forced PWM | floating (PFM, light-load efficiency) | PASS |
| 8 | U10 | 17 FB | R32 1M / R33 113k | VREF 1.204 V; VOUT 4.5-12.6 V; FB abs max 3.6 V | 1.204 x (1 + 1000/113) = 11.86 V; UNO Q VIN range 7-24 V | PASS |
| 9 | U10 | 18 COMP | R34 18k + C36 6.8 nF to GND | R5 = 2pi VOUT Rsense fC CO / ((1-D) VREF GEA), C5 = RO CO / (2 R5), C8 = RESR CO / R5 (open if < 10 pF); fC < fSW/10 and < fRHPZ/5. GEA 190 uA/V, Rsense 0.08 ohm | worst corner 5.0 V in, 1.52 A out: D 0.62, RO 7.8 ohm, CO ~30 uF effective (3 x 22 uF at 11.9 V bias), fRHPZ 81 kHz, so fC max 16 kHz. 18k gives fC about 9 kHz; ideal C5 = 6.5 nF, fitted 6.8 nF; C8 = 3 fF, left open | PASS |
| 10 | U10 | 19 ILIM | R31 150k to GND | MODE floating: ILIM = 1 190 000 / RILIM; 100k gives 10.6/11.9/13 A min/typ/max | 7.9 A typ, 7.1 A min (same spread); peak inductor current at 1.52 A out and 5.0 V in is 5.2 A; L2 Isat 10.5 A | PASS |
| 11 | U10 | 9 VIN | VBAT_B via F2 | 2.7-12 V, UVLO 2.7 V rising | 5.0-8.4 V pack | PASS |
| 12 | U3 TPS62933 | 2 EN | not connected | "drive EN high or leave the pin floating to enable"; abs max 5.5 V | floating: on whenever VBAT_F is up | PASS |
| 13 | U3 | 1 RT | not connected | RT floating = 500 kHz | floating | PASS |
| 14 | U3 | 7 SS | C10 10 nF to GND | external soft-start capacitor | 10 nF | PASS |
| 15 | U3 | 3 VIN | VBAT_F via F1 | 3.8-30 V; UVLO rising 3.4-3.8 V | 5.0-8.4 V | PASS |
| 16 | U4 PAM8302 | 1 SD | AMP_SD: R9 100k to GND, J2.1 GPIO | low = shutdown; VSH 1.2 V min, VSL 0.4 V max; start SD 1-100 ms after VDD | default off through R9, MCU drives 3.3 V high when it plays sound | PASS |
| 17 | U1 TCA9406 | 6 OE | R1 10k to +1V8, C1 4.7 uF to GND | OE referenced to VCCA; keep low while supplies come up | VCCA = +1V8 (pin 3); RC 47 ms holds OE low until both rails are up | PASS |
| 18 | U2 TCA9555 | 21 A0, 2 A1, 3 A2 | GND, +3V3, +3V3 | address 0100 A2 A1 A0 | 0x26; bus map in `sch.py`: camera 0x10, ToF 0x29, INA226 0x40, IMU 0x6B, trunk IMU 0x6A. No clash | PASS |
| 19 | U2 | 1 INT | EXP_INT: R2 10k to +3V3, J2.7 | open-drain, needs pull-up | 10k to 3.3 V, read on a 3.3 V MCU pin (Rev C fix) | PASS |
| 20 | U7 LSM6DSV16X | 1 SDO/SA0 | +3V3 | SA0 = address LSB | 0x6B | PASS |
| 21 | U7 | 12 CS | +3V3 | CS high = I2C mode | +3V3 | PASS |
| 22 | U7 | 2 SDx, 3 SCx | GND | "connect to Vdd_IO or GND if the analog hub and Qvar are disabled" | GND | PASS |
| 23 | U7 | 9 INT2, 10 OCS_Aux, 11 SDO_Aux | not connected | INT2 is an output; OCS_Aux and SDO_Aux "leave unconnected" in mode 1 | not connected | PASS |
| 24 | U8 INA226 | 2 A0, 1 A1 | GND, GND | A1 A0 = GND GND gives 0x40 | 0x40 | PASS |
| 25 | U8 | 3 ALERT | INA_ALERT: R29 10k to +3V3, J2.9 | open-drain | 10k to 3.3 V, 3.3 V MCU pin (Rev C fix) | PASS |
| 26 | U9 TTP233H-BA6 | 4 AHLB, 6 TOG | GND, GND | both have internal pull-low; 0 = active-high output, 0 = direct (not toggle) | Q high while touched | PASS |
| 27 | U5 74LVC1G126 / U6 74LVC1G125 | 1 OE | TXEN: R16 10k to GND, JP1 AUTO (Q1) or GPIO | '126 OE active high, '125 OE active low | TXEN high drives the bus (U5), low listens (U6); default low = listen | PASS |
| 28 | Q2 AON6407 | 4 G | Q2_G: R11 100k to GND | VGS max +-25 V; RDS(on) < 6 mOhm at VGS -6 V | VGS = -5.0 to -8.4 V: well inside +-25 V, fully on | PASS |
| 29 | D40 BAT54H | - | SERVO_PULLUP from +3V3 | 30 V, 200 mA | blocks servo-bus pull-up back-feed into the unpowered 3.3 V rail (Rev C fix) | PASS |

28 rows PASS, 1 row was a FAIL in Rev C before build #8 and is fixed.

## How row 1 was found

The TPS61088 pin table (datasheet p3) and section 8.3.1 say EN enables the device and
the block diagram draws the VCC LDO inside the shutdown domain. With EN tied to VCC,
VCC never rises, so EN never goes high: a latch that stays off. The UNO Q would have
had no supply on battery. The board passed DRC and ERC with this fault, because both
pins were on one legal net.

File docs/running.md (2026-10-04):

# First bring-up

In order. Nothing here needs a terminal except step 4, and that is one line.

## 1. Read the pack

Read the label before you plug it in. 5.0 to 8.4 V is safe. Two packs in series
read about 13 V and will burn every servo on the chain in seconds.

With the board already up, check what the chain is actually seeing:

    python3 software/tools/bus_volts.py

It prints every servo's voltage and one verdict line. It moves nothing.

## 2. Power on

1. UNO Q on USB-C. Wait until `http://<board address>:8938/` answers.
2. Servo supply.
3. Check the page lists every servo. A missing row is a servo with the wrong
   ID or a bad plug, not a servo that is broken.

## 3. Set zero

Hold the robot in the zero pose: legs straight down, feet flat, head level.
Then hold still for two seconds.

    python3 software/tools/zero_now.py

That is the whole calibration. Nothing is written into a servo, nothing moves,
and torque is off the entire time. It reads where every joint is and treats
that pose as zero.

It refuses a pose that is still moving, because a zero read while you are
adjusting a leg is not a zero. While it waits it prints which joint is moving
and by how much, so you know when you are still enough.

## 4. Check the inertial sensor

Tilt the robot and watch the numbers follow. This moves nothing.

    curl http://<board address>:8938/api/imu/scan     # which I2C bus and address answered
    curl http://<board address>:8938/api/imu          # one sample: accelerometer and gyro

Tilt it and read `/api/imu` again. If the numbers do not change, the sensor is
not working, whatever the scan said. A still robot and a frozen chip look
identical in a log, so move it before you believe it.

Do not poll the scan in a loop. With nothing answering it probes several
hundred addresses with a timeout each, on a microcontroller that serves one
request at a time, and it will starve the servo bus while it does.

## 5. Move one joint

Open `http://<board address>:8938/?control`.

Pick one servo. Press **Enable slider**: it holds that servo where it is, at
30 % torque, and reads back that it held. Move the slider a little. Press
**Release** to turn torque off again.

If the slider is disabled, that servo has no recorded angle band yet. Record
one first, see [servos.md](servos.md).

## When the bus stops answering

Hot-plugging a servo while the bus is running can wedge the MCU. The daemon
notices within a second, restarts the MCU app once, which takes about twenty
seconds, and carries on; the page says what happened. If that does not help it
waits rather than restarting again, and tries once more the moment the bus
answers.

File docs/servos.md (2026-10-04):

# Servos

Fifteen Feetech STS-protocol bus servos, one chain, 1 Mbit/s. We use the
HD-1910-C001. Any STS servo that speaks the same protocol will answer.

## The IDs

The numbering follows Open Duck Mini: right leg in the tens, left leg in the
twenties, head in the thirties.

| ID | joint | | ID | joint |
|---|---|---|---|---|
| 10 | right hip yaw | | 20 | left hip yaw |
| 11 | right hip roll | | 21 | left hip roll |
| 12 | right hip pitch | | 22 | left hip pitch |
| 13 | right knee | | 23 | left knee |
| 14 | right ankle | | 24 | left ankle |
| 30 | neck pitch | | 33 | head roll |
| 31 | head pitch | | 34 | mouth |
| 32 | head yaw | | | |

The same table as data: `software/servo-bus/servo-ids.json`.

## Setting them

Every servo leaves the factory at ID 1, so plug them in one at a time.

1. Plug in one servo. It shows up on the page as ID 1 within two seconds.
2. Press **Set ID** on its row, type the new ID and the joint name, confirm.
3. Unplug it, plug in the next one.

The page refuses the change when the servo does not answer thirty reads out of
thirty cleanly, which is what two servos on one ID looks like; when the new ID
already answers on the bus; or when the new ID is already recorded for another
joint, plugged in or not. It then offers you a free temporary ID between 101
and 199.

After the write it checks thirty clean reads at the new ID, that the old ID is
gone, and that the ID register reads back. Then it sets maximum torque and the
torque limit to 30 % and turns torque off.

Every change is kept with the time, the old ID, the new ID and the joint, in
`/home/arduino/servo-bus-ids.json` on the board, shown at the bottom of the
page.

## Angle limits

A servo with no recorded band cannot be driven. This is deliberate: the mouth
rests inside about twenty degrees of travel and a hip swings two hundred, and
one global band that suits the hip will tear the jaw off.

To record one:

1. Press **Record** on the servo's card. Torque goes off.
2. Turn that joint by hand, slowly, from one end stop to the other.
3. Press **Save**.

The saved band is the ends you reached minus three degrees each side. It goes
into the servo's own EEPROM and is read back. A recording that jumps more than
half a turn is marked wrapped and the save is refused; so is a band under about
five degrees.

From the command line instead: `software/tools/record_limits.py`, then
`software/tools/limits_table.py` to see them all.

## Power

5.0 to 8.4 V. Read the label on your pack before you plug it in. Two packs in
series read about 13 V and will destroy every servo on the chain in seconds.
The daemon refuses to torque anything above 8.4 V, but a guard is not a reason
to plug in a pack nobody read.

Check the bus any time, without starting anything and without moving anything:

    python3 software/tools/bus_volts.py

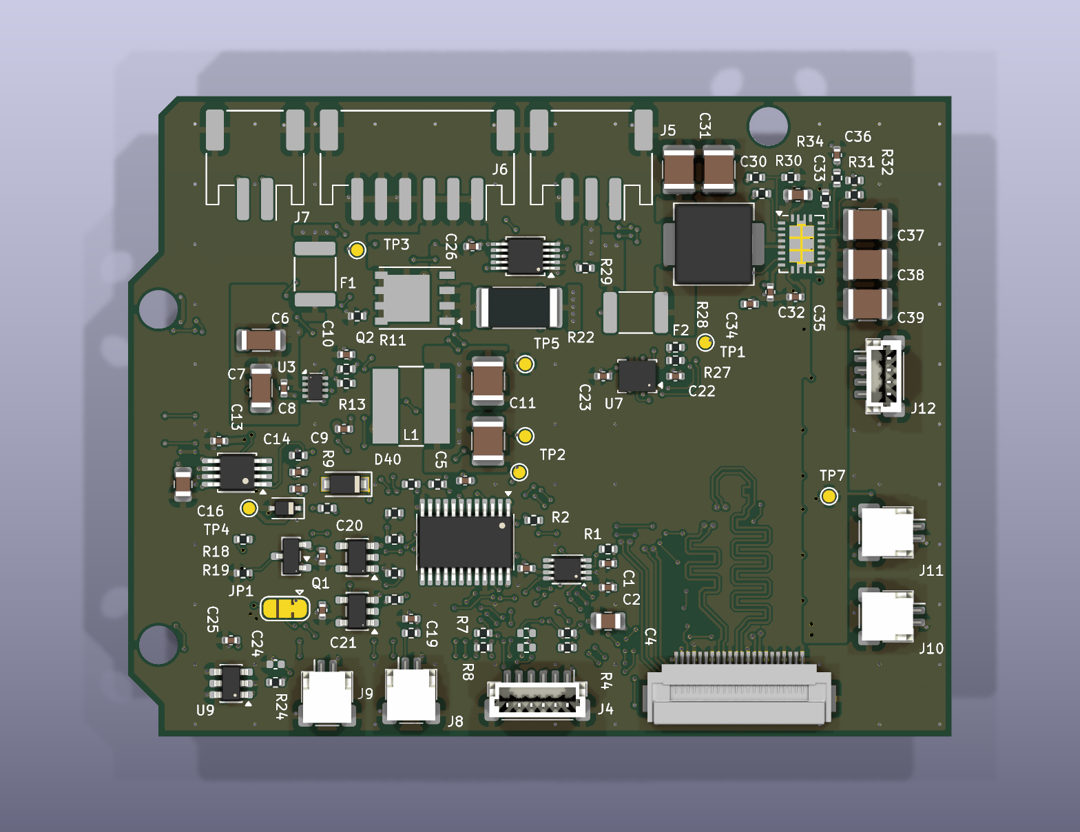
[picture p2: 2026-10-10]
electronics/hat/img/bottom.png

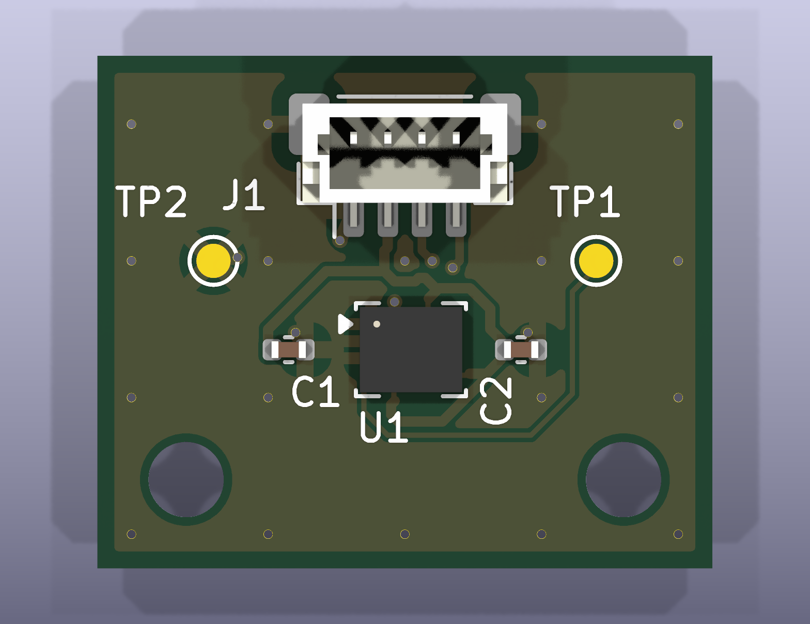
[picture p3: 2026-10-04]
electronics/imu-board/img/top.png

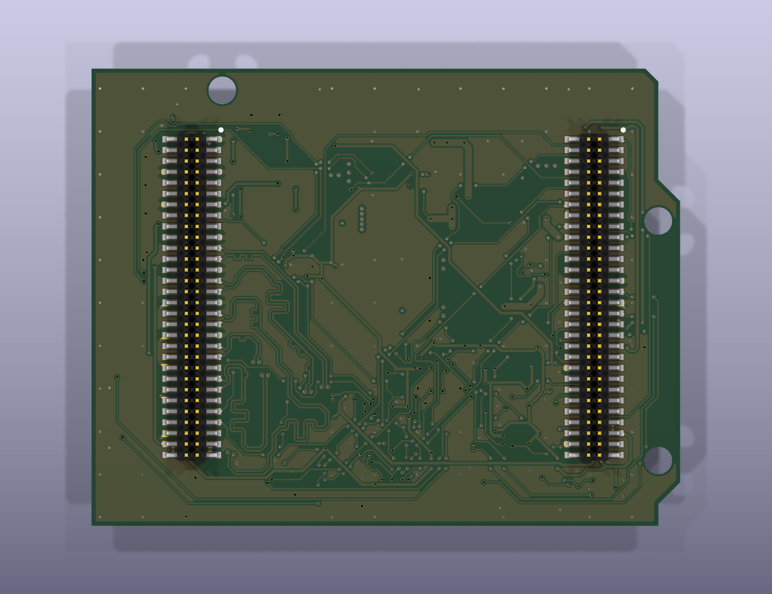
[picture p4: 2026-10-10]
electronics/hat/img/top.png

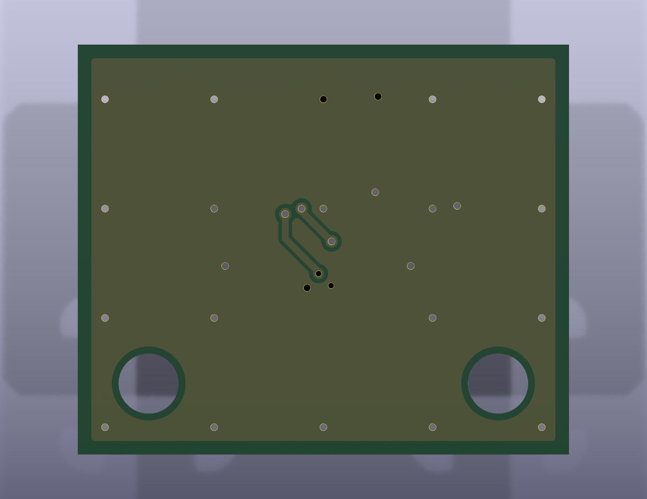
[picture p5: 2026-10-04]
electronics/imu-board/img/bottom.png

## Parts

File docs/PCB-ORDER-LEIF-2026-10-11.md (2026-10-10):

# Order the UNO Q head hat, Rev C (for Leif, 2026-10-11)

foreman/microduck-assembly.60, written 2026-10-10. Branch `foreman/devkit-pcb` of
walking-robot-kit. Nothing has been ordered or paid.

## Your one step

1. Open https://cart.jlcpcb.com/quote, signed in as you.
2. Upload `electronics/hat/fab/gerbers.zip`, set the options in the table below.
3. Turn on **PCB Assembly**, upload `electronics/hat/fab/bom.csv` and `electronics/hat/fab/cpl.csv`.
4. In JLC's placement preview, check the three parts in the "Look at these" list, then pay.

About 15 minutes. Everything else is done and checked.

## Files (all in `electronics/hat/`)

Download links (30 days, same bytes as the hashes below; checked by foreman/microduck-assembly 2026-10-10 17:10 CEST):
[gerbers.zip](https://media.ce-net.com/o/5cdad18f8c704fcf229e312edadb4709ed78da27125f4068d5a359474794430f.zip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) ·
[bom.csv](https://media.ce-net.com/o/5f05a8434ca9145fbedfdcf7bfce9ce96e01fe3ac6b7256be1dc7a8af0f17434.csv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) ·
[cpl.csv](https://media.ce-net.com/o/4b424a0854ed8e4dba3355d99951e6e669d14866a8e7db7097f7a5bac97cdfcf.csv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)

| file | what | sha256 (first 12) |
|---|---|---|
| `fab/gerbers.zip` | 4-layer gerbers + drills, 31 files | 5cdad18f8c70 |
| `fab/bom.csv` | JLC BOM, 55 lines, every line with an LCSC number | 5f05a8434ca9 |
| `fab/cpl.csv` | JLC placement, 95 parts: 93 bottom, 2 top (J1, J2) | 4b424a0854ed |

Pictures: `img/top.png`, `img/bottom.png`, `img/iso.png`. 3D: `3d/unoq_hat.step`.
Schematic: `schematic.pdf`.

## JLCPCB options

| option | set to | why |
|---|---|---|
| Base material | FR-4 | |
| Layers | 4 | JLC's parser read "4 layer board of 53.34x68.58mm" on Rev B; Rev C has the same outline |
| Dimensions | 68.58 x 53.34 mm | UNO outline |
| PCB qty | 5 | |
| Thickness | 1.6 mm | matches the Arduino carrier |
| Color / silk | green / white | cheapest, fastest |
| Material | FR4 TG155 | JLC forces it with the finer via class |
| Surface finish | **ENIG 1U"** | flat pads for 0.5 mm pitch parts (U10 VQFN, U1, U3, U8, J3 FFC) and the 1.27 mm board-to-board rows |
| Outer / inner copper | 1 oz / 0.5 oz | |
| Via covering | plugged (tented is fine too) | |
| **Min via hole / diameter** | **0.2 mm (0.3/0.35)** | one via inside the IMU's LGA is 0.20/0.40 mm; all others 0.25/0.45 |
| Board outline tolerance | +-0.2 mm | |
| Electrical test | flying probe | |
| Remove order number | yes (if free) | |
| **PCB Assembly** | **yes, Standard, both sides**, qty 5 | J1/J2 on top, everything else on the bottom |
| Tooling holes | added by JLC | |
| Confirm parts placement | yes | lets you see JLC's preview before it builds |

## Price

| item | amount | source |
|---|---|---|
| Bare boards, 5 pcs, these options | about $62 | live JLC quote of Rev B on 2026-10-03 (same size, layers, ENIG, TG155): $62.02. Rev C's 0.2 mm via class is one step finer, so expect a few dollars more |
| DHL DDP to you | about $31 | same quote, 2-4 business days |
| Assembly setup + stencils, two sides | about $50-70 | JLC Standard PCBA fees as published; the page shows the exact number |
| Extended-part fees | up to $123 | 41 lines JLC lists as extended at $3 each; "preferred" ones are free |
| Components, 5 boards | about $70 | $13.67 per board at LCSC 10+ prices (`electronics/hat/docs/BOM-REV-C.md`) |
| **Total, 5 assembled boards to your door** | **about $300-360** | the quote page is the real number; pay only if it is under $400 |

## Look at these in JLC's placement preview

1. **J1, J2** (top side, the two 2x30 1.27 mm board-to-board connectors): the only two top
   parts. They must sit on the two long pad rows.
2. **U10** (TPS61088, bottom, near the J1 end): pin-1 dot of the chip at the corner nearest C33.
3. **U7** (LSM6DSV16X, bottom, small 2.5 x 3 mm square): pin-1 dot matches the board dot.

Bottom-side rotations are the usual mistake. If any part sits rotated by 90 or 180, fix it in
the preview (drag-rotate) before paying.

## The JLCPCB quote from Kris is for Rev B

Kris at JLCPCB (support@jlcpcb.com) sent a quote on 2026-10-05, in your leif@rydenfalk.com
inbox. It was for **Rev B**. Rev C changed the power block (new boost U10, inductor L2, fuse
F2, D40, the 6-pin J6, the EN divider), so that quote does not apply. Order Rev C through the
web quote above, or ask Kris to redo it with these three files. Nobody has emailed JLCPCB.

## What Rev C fixes (the three HOLD findings from the 2026-10-07 audit)

| # | Rev B fault | Rev C fix |
|---|---|---|
| 1 | IMU, expander and pack-monitor interrupts drove 3.3 V into 1.8 V SoC pins (J2.37/39/41) | moved to 3.3 V MCU pins J2.3, J2.7, J2.9 |
| 2 | the hat's 5 V drove JMISC 54/56, which is USB VBUS on the UNO Q | hat no longer touches 54/56; a TPS61088 boost makes 11.86 V into the UNO Q's own VIN (7-24 V) on J1.57/59 |
| 3 | servo bus pull-ups back-fed +3V3 from a powered bus | D40 (BAT54H) blocks it |

Found and fixed on 2026-10-10 while checking Rev C (none of these show in DRC or ERC):

| # | fault | fix |
|---|---|---|
| 4 | U10 EN tied to VCC, an LDO that EN itself turns on: the boost would never start | R35/R36 100k/100k divider from the pack: 2.5 V at 5.0 V, 4.2 V at 8.4 V (EN max 7 V) |
| 5 | a 0.09 mm clearance rule in the JLC rule file let the ground pour into the JMEDIA pads' mask openings (83 bridges) | rule removed; pour back at 0.127 mm |
| 6 | J6 (two contacts per pole, 4 A) below the 4.7 A worst case | J6 is a 6-pin PH, three contacts per pole, 6 A |

## Checks (all on the files above)

| check | result | file |
|---|---|---|
| KiCad DRC, board rules | 0 errors, 0 warnings, 0 unconnected | `electronics/hat/checks/drc-build.json` |
| KiCad DRC with JLC rule file | 0 errors, 0 warnings, 0 unconnected | `checks/drc-jlc-rules.json` |
| KiCad ERC | 0 errors, 0 warnings | `checks/erc.json` |
| schematic vs board | 75 of 75 nets agree | `checks/build-summary.json` |
| ce-fabmcp pcb_drc | In1, In2 PASS at 0.127 mm; F.Cu, B.Cu "FAIL" from its circle approximation of fine-pitch rectangular pads, not real (KiCad's polygon DRC on the same copper is 0) | `checks/pcb-drc-fabmcp.json` |
| footprints vs datasheets | 51 of 51 PASS | `electronics/hat/docs/FOOTPRINTS-REV-C.md` |
| strap pins vs datasheets | 29 rows: 1 fault found and fixed (EN), 28 PASS | `electronics/hat/docs/STRAP-PINS-REV-C.md` |
| power budget | every rail has margin at the worst case; tightest are F2 (20 %) and J6 (21 %) | `electronics/hat/docs/POWER-BUDGET-REV-C.md` |
| BOM stock | 51 lines, 0 short for 5 boards, fetched 2026-10-10 14:53 UTC; tightest line J1/J2 (782 in stock for 10) | `electronics/hat/docs/BOM-REV-C.md` |

## Known limits of the first 5 boards

- J1/J2 are BOOMELE C191721, an equivalent of Arduino's Greenconn GPEC212 header. Pads and
  pitch match Arduino's carrier files exactly; the first boards are the fit test on a real UNO Q.
- Seven basic parts show 0 at the LCSC shop and 200 k to 20 M at JLC's own stock. JLC
  assembles from its own stock, so they are fine.
- Servo power does not go through this board. J5 pin 2 is a VBAT reference only (2 A contact).

## Kit line item: J6-to-XT30 pack lead

Buyers own a 2S pack with an XT30, not a 6-pin PH lead, so the kit ships this pigtail:

| part | LCSC | JLC stock (2026-10-10 14:53 UTC) | per lead |
|---|---|---|---|
| JST PHR-6 housing | C157952 | 58,616 | 1 |
| JST SPH-002T-P0.5S crimp contact | C111515 | 1,244,656 | 6 |
| Amass XT30U-F (female plug; check it mates the pack you test with) | C99102 | 48,043 | 1 |
| wire, 24 AWG silicone, red x3 + black x3, 150 mm | - | - | 6 |

PH crimps take 24-30 AWG only, so 20 AWG cannot go into the housing: the lead is six 24 AWG
wires, pins 1-3 red joined into the XT30 +, pins 4-6 black into the XT30 -. Three 24 AWG in
parallel carry the same as one 19 AWG. A harness shop in Huaqiangbei can make it. Check polarity with a meter before
the first plug-in: J6 pins 1-3 are pack +.

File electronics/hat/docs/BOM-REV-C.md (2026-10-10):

# Rev C bill of materials, stock checked live

foreman/microduck-assembly.60. Generated by `tools/bom_doc.py` from `data/bom-stock.json`, which `tools/bom_stock.py` fetched from LCSC and the JLCPCB SMT parts list at **2026-10-10T21:03:33Z** for a build of **5 boards**.

JLC stock is what the assembly line places from; LCSC stock is the retail shop. A line is OK when JLC holds at least the quantity the build needs. Seven basic parts show 0 at the LCSC shop and hundreds of thousands to millions at JLC; JLC assembles from its own stock, so they are OK.

| refs | qty/board | LCSC | MPN | maker | package | JLC stock | need | LCSC stock | JLC library | USD each (10+) | OK |
|---|---|---|---|---|---|---|---|---|---|---|---|
| J1, J2 | 2 | [C191721](https://www.lcsc.com/product-detail/C191721.html) | 1.27-2*30P | BOOMELE(Boom Precision Elec) | SMD,P=1.27mm | 782 | 10 | 782 | expand | 0.3731 | yes |
| J3 | 1 | [C3169786](https://www.lcsc.com/product-detail/C3169786.html) | TF31-22S-0.5SH(800) | HRS | SMD,P=0.5mm,Surface Mount,Right Angle | 1,065 | 5 | 1,044 | expand | 0.3973 | yes |
| U1 | 1 | [C840107](https://www.lcsc.com/product-detail/C840107.html) | TCA9406DCUR | TI | VSSOP-8-0.5mm | 16,529 | 5 | 16,412 | expand | 0.6883 | yes |
| R1, R2, R7, R8, R15, R16, R17, R18, R29, R25, R26 | 11 | [C25744](https://www.lcsc.com/product-detail/C25744.html) | 0402WGF1002TCE | UNI-ROYAL | 0402 | 19,787,752 | 55 | 0 | base | 0.0034 | yes |
| C1 | 1 | [C23733](https://www.lcsc.com/product-detail/C23733.html) | CL05A475MP5NRNC | Samsung Electro-Mechanics | 0402 | 2,105,890 | 5 | 992,750 | base | 0.0167 | yes |
| C2, C3, C5, C19, C20, C21, C13, C14, C15, C22, C23, C26, C25 | 13 | [C1525](https://www.lcsc.com/product-detail/C1525.html) | CL05B104KO5NNNC | Samsung Electro-Mechanics | 0402 | 24,115,321 | 65 | 6,032,000 | base | 0.0046 | yes |
| U2 | 1 | [C465732](https://www.lcsc.com/product-detail/C465732.html) | TCA9555PWR | TI | TSSOP-24 | 38,408 | 5 | 37,613 | expand | 0.5939 | yes |
| C4, C16 | 2 | [C1713](https://www.lcsc.com/product-detail/C1713.html) | CL21A106KOQNNNE | Samsung Electro-Mechanics | 0805 | 325,371 | 10 | 0 | expand | 0.0883 | yes |
| J4 | 1 | [C160392](https://www.lcsc.com/product-detail/C160392.html) | BM06B-SRSS-TB(LF)(SN) | JST | SMD,P=1mm | 30,877 | 5 | 14,105 | expand | 0.3490 | yes |
| R3, R4 | 2 | [C17168](https://www.lcsc.com/product-detail/C17168.html) | 0402WGF0000TCE | UNI-ROYAL | 0402 | 8,049,052 | 10 | 0 | base | 0.0025 | yes |
| J8, J9, J10, J11 | 4 | [C160402](https://www.lcsc.com/product-detail/C160402.html) | SM02B-SRSS-TB(LF)(SN) | JST | SMD,P=1mm,Surface Mount,Right Angle | 27,257 | 20 | 27,255 | expand | 0.1333 | yes |
| R14 | 1 | [C25879](https://www.lcsc.com/product-detail/C25879.html) | 0402WGF2201TCE | UNI-ROYAL | 0402 | 1,606,911 | 5 | 0 | base | 0.0018 | yes |
| U5 | 1 | [C7834](https://www.lcsc.com/product-detail/C7834.html) | SN74LVC1G126DBVR | TI | SOT-23-5 | 64,139 | 5 | 63,550 | expand | 0.0755 | yes |
| U6 | 1 | [C23654](https://www.lcsc.com/product-detail/C23654.html) | SN74LVC1G125DBVR | TI | SOT-23-5 | 60,384 | 5 | 60,380 | expand | 0.0753 | yes |
| Q1 | 1 | [C727128](https://www.lcsc.com/product-detail/C727128.html) | MMBT3906 | TWGMC | SOT-23 | 383,664 | 5 | 383,650 | expand | 0.0073 | yes |
| R19 | 1 | [C25765](https://www.lcsc.com/product-detail/C25765.html) | 0402WGF2002TCE | UNI-ROYAL | 0402 | 2,661,288 | 5 | 979,500 | base | 0.0013 | yes |
| R20 | 1 | [C138002](https://www.lcsc.com/product-detail/C138002.html) | RC0402FR-0733RL | YAGEO | 0402 | 7,301,324 | 5 | 6,941,700 | expand | 0.0036 | yes |
| R21, R24 | 2 | [C106235](https://www.lcsc.com/product-detail/C106235.html) | RC0402FR-071KL | YAGEO | 0402 | 2,016,284 | 10 | 1,030,200 | expand | 0.0038 | yes |
| D1 | 1 | [C151348](https://www.lcsc.com/product-detail/C151348.html) | BZT52C5V1S-7-F | DIODES | SOD-323 | 68,335 | 5 | 68,180 | expand | 0.0355 | yes |
| D40 | 1 | [C426769](https://www.lcsc.com/product-detail/C426769.html) | BAT54H,115 | Nexperia | SOD-123F | 7,930 | 5 | 7,885 | expand | 0.1452 | yes |
| J6 | 1 | [C265405](https://www.lcsc.com/product-detail/C265405.html) | S6B-PH-SM4-TB(LF)(SN) | JST | SMD,P=2mm,Surface Mount,Right Angle | 5,096 | 5 | 5,096 | expand | 0.3185 | yes |
| Q2 | 1 | [C13899](https://www.lcsc.com/product-detail/C13899.html) | AON6407 | AOS | PDFN-8(5.8x4.9) | 8,327 | 5 | 8,327 | expand | 0.6899 | yes |
| R11, R13, R9, R35, R36 | 5 | [C25741](https://www.lcsc.com/product-detail/C25741.html) | 0402WGF1003TCE | UNI-ROYAL | 0402 | 8,085,679 | 25 | 1,400,600 | base | 0.0025 | yes |
| F1 | 1 | [C702820](https://www.lcsc.com/product-detail/C702820.html) | SMD1812P300TF/16 | RUILON | 1812 | 9,061 | 5 | 9,060 | expand | 0.1986 | yes |
| U3 | 1 | [C3200405](https://www.lcsc.com/product-detail/C3200405.html) | TPS62933DRLR | TI | SOT-583 | 32,491 | 5 | 30,593 | expand | 0.4882 | yes |
| C6, C7 | 2 | [C77090](https://www.lcsc.com/product-detail/C77090.html) | GRM31CR61E106KA12L | muRata | 1206 | 18,153 | 10 | 12,070 | expand | 0.1677 | yes |
| C8, C9, C32, C34 | 4 | [C105883](https://www.lcsc.com/product-detail/C105883.html) | CC0402KRX7R8BB104 | YAGEO | 0402 | 2,106,739 | 20 | 1,597,100 | expand | 0.0073 | yes |
| C10 | 1 | [C60133](https://www.lcsc.com/product-detail/C60133.html) | CC0402KRX7R9BB103 | YAGEO | 0402 | 6,919,092 | 5 | 6,589,800 | expand | 0.0042 | yes |
| R12 | 1 | [C27011](https://www.lcsc.com/product-detail/C27011.html) | 0402WGF5233TCE | UNI-ROYAL | 0402 | 6,161 | 5 | 6,100 | expand | 0.0015 | yes |
| L1 | 1 | [C168072](https://www.lcsc.com/product-detail/C168072.html) | FNR6045S6R8MT | cjiang | SMD,6x6mm | 650 | 5 | 650 | expand | 0.1130 | yes |
| C11, C12, C30, C31, C37, C38, C39 | 7 | [C52306](https://www.lcsc.com/product-detail/C52306.html) | CL32A226KAJNNNE | Samsung Electro-Mechanics | 1210 | 278,940 | 35 | 220,532 | expand | 0.1634 | yes |
| J5 | 1 | [C265101](https://www.lcsc.com/product-detail/C265101.html) | S3B-PH-SM4-TB(LF)(SN) | JST | SMD,P=2mm,Surface Mount,Right Angle | 867 | 5 | 865 | expand | 0.2826 | yes |
| U4 | 1 | [C113367](https://www.lcsc.com/product-detail/C113367.html) | PAM8302AASCR | DIODES | MSOP-8 | 13,250 | 5 | 13,250 | expand | 0.3220 | yes |
| J7 | 1 | [C295747](https://www.lcsc.com/product-detail/C295747.html) | S2B-PH-SM4-TB(LF)(SN) | JST | SMD,P=2mm,Surface Mount,Right Angle | 15,277 | 5 | 15,275 | expand | 0.2387 | yes |
| U7 | 1 | [C5267406](https://www.lcsc.com/product-detail/C5267406.html) | LSM6DSV16XTR | ST | LGA-14(2.5x3) | 7,588 | 5 | 7,121 | expand | 2.9938 | yes |
| R27, R28 | 2 | [C25900](https://www.lcsc.com/product-detail/C25900.html) | 0402WGF4701TCE | UNI-ROYAL | 0402 | 14,597,579 | 10 | 7,340,200 | base | 0.0027 | yes |
| J12 | 1 | [C160390](https://www.lcsc.com/product-detail/C160390.html) | BM04B-SRSS-TB(LF)(SN) | JST | SMD,P=1mm | 25,132 | 5 | 22,220 | expand | 0.2559 | yes |
| R22 | 1 | [C185817](https://www.lcsc.com/product-detail/C185817.html) | RLM25FEER005 | TA-I Tech | 2512 | 89,469 | 5 | 88,700 | expand | 0.0530 | yes |
| U8 | 1 | [C49851](https://www.lcsc.com/product-detail/C49851.html) | INA226AIDGSR | TI | VSSOP-10 | 53,086 | 5 | 47,825 | expand | 0.6380 | yes |
| U9 | 1 | [C2890349](https://www.lcsc.com/product-detail/C2890349.html) | TTP233H-BA6 | TONTEK | SOT-23-6L | 8,576 | 5 | 8,575 | expand | 0.1162 | yes |
| U10 | 1 | [C87357](https://www.lcsc.com/product-detail/C87357.html) | TPS61088RHLR | TI | VQFN-20-EP(3.6x4.6) | 4,090 | 5 | 2,602 | expand | 1.0391 | yes |
| L2 | 1 | [C167218](https://www.lcsc.com/product-detail/C167218.html) | FXL0630-2R2-M | cjiang | SMD,7x6.6mm | 62,964 | 5 | 62,960 | expand | 0.1695 | yes |
| F2 | 1 | [C2844238](https://www.lcsc.com/product-detail/C2844238.html) | JK-MSMD500L-12V | Jinrui | 1812 | 4,501 | 5 | 4,385 | expand | 0.2127 | yes |
| C33 | 1 | [C19666](https://www.lcsc.com/product-detail/C19666.html) | CL10A475KO8NNNC | Samsung Electro-Mechanics | 0603 | 2,212,841 | 5 | 77,490 | base | 0.0298 | yes |
| C35 | 1 | [C82219](https://www.lcsc.com/product-detail/C82219.html) | 0402B473K500NT | FH | 0402 | 215,768 | 5 | 215,700 | expand | 0.0060 | yes |
| R30 | 1 | [C25774](https://www.lcsc.com/product-detail/C25774.html) | 0402WGF3003TCE | UNI-ROYAL | 0402 | 210,240 | 5 | 0 | expand | 0.0019 | yes |
| R31 | 1 | [C25755](https://www.lcsc.com/product-detail/C25755.html) | 0402WGF1503TCE | UNI-ROYAL | 0402 | 257,327 | 5 | 106,600 | expand | 0.0014 | yes |
| R32 | 1 | [C26083](https://www.lcsc.com/product-detail/C26083.html) | 0402WGF1004TCE | UNI-ROYAL | 0402 | 2,223,764 | 5 | 411,900 | base | 0.0026 | yes |
| R33 | 1 | [C25746](https://www.lcsc.com/product-detail/C25746.html) | 0402WGF1133TCE | UNI-ROYAL | 0402 | 52,263 | 5 | 52,200 | expand | 0.0009 | yes |
| R34 | 1 | [C25762](https://www.lcsc.com/product-detail/C25762.html) | 0402WGF1802TCE | UNI-ROYAL | 0402 | 483,177 | 5 | 335,200 | expand | 0.0014 | yes |
| C36 | 1 | [C1542](https://www.lcsc.com/product-detail/C1542.html) | 0402B682K500NT | FH | 0402 | 97,585 | 5 | 34,600 | expand | 0.0054 | yes |

51 lines, 0 short. Parts per board at LCSC 10+ prices: **$13.67**. Tightest line: C191721 (J1, J2), JLC stock 782 for a need of 10.

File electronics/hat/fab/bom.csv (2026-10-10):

Comment | Designator | Footprint | LCSC Part #
4.7uF | C1 | C_0402_1005Metric | C23733
10nF | C10 | C_0402_1005Metric | C60133
22uF 25V | C11,C12,C30,C31,C37,C38,C39 | C_1210_3225Metric | C52306
100nF | C2,C3,C5,C19,C20,C21,C13,C14,C15,C22,C23,C26,C25 | C_0402_1005Metric | C1525
4.7uF 16V | C33 | C_0603_1608Metric | C19666
47nF | C35 | C_0402_1005Metric | C82219
6.8nF | C36 | C_0402_1005Metric | C1542
10uF 16V | C4,C16 | C_0805_2012Metric | C1713
10uF 25V | C6,C7 | C_1206_3216Metric | C77090
100nF 25V | C8,C9,C32,C34 | C_0402_1005Metric | C105883
BZT52C5V1S | D1 | D_SOD-323 | C151348
BAT54H,115 | D40 | BAT54H_Nexperia_SOD123F | C426769
SMD1812P300TF/16 3A PTC | F1 | Fuse_1812_4532Metric | C702820
JK-MSMD500L-12V 5A PTC | F2 | Fuse_1812_4532Metric | C2844238
JMEDIA 2x30 1.27 SMD male (GPEC212-3002A011C1AF equiv.) | J1 | UNOQ_JMEDIA_2x30_P1.27_Male | C191721
SM02B-SRSS-TB left foot contact | J10 | JST_SH_SM02B-SRSS-TB_1x02-1MP_P1.00mm_Horizontal | C160402
SM02B-SRSS-TB right foot contact | J11 | JST_SH_SM02B-SRSS-TB_1x02-1MP_P1.00mm_Horizontal | C160402
BM04B-SRSS-TB trunk IMU I2C | J12 | JST_SH_BM04B-SRSS-TB_1x04-1MP_P1.00mm_Vertical | C160390
JMISC 2x30 1.27 SMD male (GPEC212-3002A011C1AF equiv.) | J2 | UNOQ_JMEDIA_2x30_P1.27_Male | C191721
TF31-22S-0.5SH 22p 0.5 FFC (IMX219) | J3 | FFC_22P_P0.5_TF31-22S | C3169786
BM06B-SRSS-TB ToF | J4 | JST_SH_BM06B-SRSS-TB_1x06-1MP_P1.00mm_Vertical | C160392
S3B-PH-SM4-TB servo bus | J5 | JST_PH_S3B-PH-SM4-TB_1x03-1MP_P2.00mm_Horizontal | C265101
S6B-PH-SM4-TB 2S pack in | J6 | JST_PH_S6B-PH-SM4-TB_1x06-1MP_P2.00mm_Horizontal | C265405
S2B-PH-SM4-TB speaker | J7 | JST_PH_S2B-PH-SM4-TB_1x02-1MP_P2.00mm_Horizontal | C295747
SM02B-SRSS-TB electret mic | J8 | JST_SH_SM02B-SRSS-TB_1x02-1MP_P1.00mm_Horizontal | C160402
SM02B-SRSS-TB touch pad | J9 | JST_SH_SM02B-SRSS-TB_1x02-1MP_P1.00mm_Horizontal | C160402
FNR6045S6R8MT 6.8uH 3.3A | L1 | FNR6045_6.0x6.0mm | C168072
FXL0630-2R2-M 2.2uH | L2 | L_Changjiang_FXL0630 | C167218
MMBT3906 | Q1 | SOT-23 | C727128
AON6407 reverse-polarity P-FET | Q2 | PowerPAK_SO-8_Single | C13899
10k | R1,R2,R7,R8,R15,R16,R17,R18,R29,R25,R26 | R_0402_1005Metric | C25744
100k | R11,R13,R9,R35,R36 | R_0402_1005Metric | C25741
523k | R12 | R_0402_1005Metric | C27011
2.2k | R14 | R_0402_1005Metric | C25879
20k | R19 | R_0402_1005Metric | C25765
33R | R20 | R_0402_1005Metric | C138002
1k | R21,R24 | R_0402_1005Metric | C106235
5mR 2W shunt | R22 | R_2512_6332Metric | C185817
4.7k | R27,R28 | R_0402_1005Metric | C25900
0R | R3,R4 | R_0402_1005Metric | C17168
300k | R30 | R_0402_1005Metric | C25774
150k | R31 | R_0402_1005Metric | C25755
1M | R32 | R_0402_1005Metric | C26083
113k | R33 | R_0402_1005Metric | C25746
18k | R34 | R_0402_1005Metric | C25762
TCA9406DCUR | U1 | VSSOP-8_2.3x2mm_P0.5mm | C840107
TPS61088RHLR | U10 | Texas_VQFN-RHL-20 | C87357
TCA9555PWR | U2 | TSSOP-24_4.4x7.8mm_P0.65mm | C465732
TPS62933DRLR | U3 | SOT-583-8 | C3200405
PAM8302AASCR | U4 | MSOP-8_3x3mm_P0.65mm | C113367
SN74LVC1G126DBVR | U5 | SOT-23-5 | C7834
SN74LVC1G125DBVR | U6 | SOT-23-5 | C23654
LSM6DSV16X | U7 | LGA-14_3x2.5mm_P0.5mm_LayoutBorder3x4y | C5267406
INA226AIDGSR | U8 | TSSOP-10_3x3mm_P0.5mm | C49851
TTP233H-BA6 | U9 | SOT-23-6 | C2890349

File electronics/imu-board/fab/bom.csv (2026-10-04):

Comment | Designator | Footprint | LCSC Part #
100nF | C1,C2 | C_0402_1005Metric | C1525
BM04B-SRSS-TB I2C in | J1 | JST_SH_BM04B-SRSS-TB_1x04-1MP_P1.00mm_Vertical | C160390
LSM6DSV16X | U1 | LGA-14_3x2.5mm_P0.5mm_LayoutBorder3x4y | C5267406

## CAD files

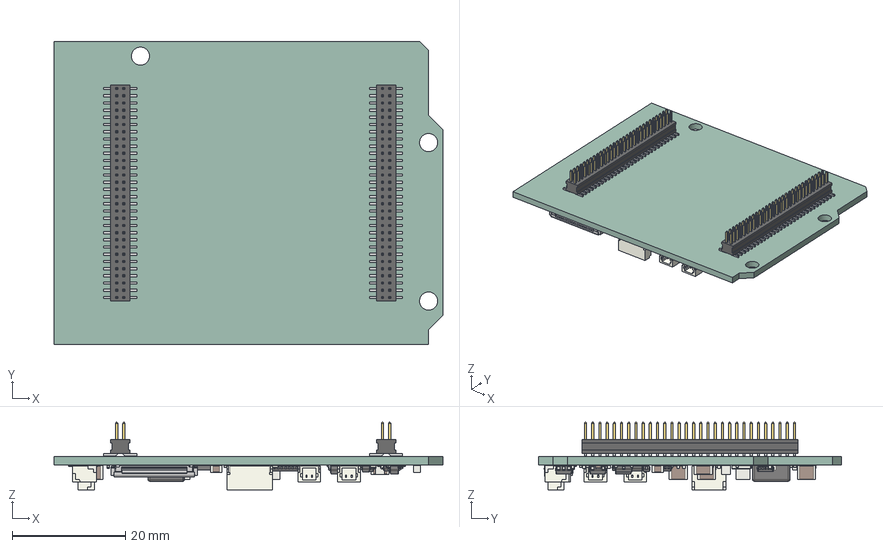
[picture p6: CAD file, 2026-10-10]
electronics/hat/3d/unoq_hat.step
68.6 x 53.3 x 12.0 mm
FTSH-130-01-L-DV_body x 2
FTSH-130-01-L-DV_pins1 x 2
FTSH-130-01-L-DV_pins2 x 2
R_0402_1005Metric x 33
C_0402_1005Metric x 22
C_0603_1608Metric
C_1210_3225Metric x 7
C_1206_3216Metric x 2
L_Changjiang_FXL0630
LGA_14_3x25mm_P05mm_LayoutBorder3x4y
SOT-583-8
TF31-22S-0_5SH-233490.PRT
JST_SH_BM06B-SRSS-TB_1x06-1MP_P1.00mm_Vertical
JST_SH_SM02B-SRSS-TB_1x02-1MP_P1.00mm_Horizontal x 4
C_0805_2012Metric x 2
TSSOP-24_4.4x7.8mm_P0.65mm
D_SOD-323
D_SOD_123F
VSSOP-8_2.3x2mm_P0.5mm
SOT-23-6
SOT-23-5 x 2
TSSOP-10_3x3mm_P0.5mm
JST_SH_BM04B-SRSS-TB_1x04-1MP_P1.00mm_Vertical
R_2512_6332Metric
SOT-23
MSOP-8_3x3mm_P0.65mm
unoq_hat_PCB

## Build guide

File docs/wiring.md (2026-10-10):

# Wiring

## The servo chain

One 3-pin plug on the hat: signal, supply, ground. The servos daisy-chain from
there, any order. Signal is half duplex on Serial1, which is D0 and D1 on the
UNO Q, at 1 Mbit/s. The hat switches the direction in hardware, so nothing in
the firmware has to drive a transmit-enable pin.

Without the hat, a URT-2 adapter on D0 and D1 does the same job, and everything
in `software/` works unchanged. You lose the camera, the audio, the distance
sensor, the pack monitor and the foot contacts.

Servo power does not come from the board. Give the chain its own supply between
5.0 and 8.4 V and share the ground with the board.

The hat takes the 2S pack on J6, a 6-pin JST PH: pins 1-3 are pack +, 4-6 are
ground. The kit's lead goes from J6 to an XT30. Do not feed servo current
through J5; its pin 2 is a pack-voltage reference with a 2 A contact.

## The inertial sensor

The hat carries an LSM6DSV16X at 0x6B and you do not have to wire anything.

If you are using a bare UNO Q with a loose MPU-6050 module, four wires:

| module | UNO Q | which pin |
|---|---|---|
| SCL | D21 | top row, first pin (PB10) |
| SDA | D20 | top row, second pin (PB11) |
| VCC | 3.3V | bottom row, fourth pin. Never 5V, never VIN |
| GND | GND | bottom row, sixth pin |

Those header pins are I2C2, which the Arduino core calls `Wire`. The Qwiic
socket is a different bus, I2C4, called `Wire1`. You do not have to know which
one you used: the firmware probes all of them and reports which answered.

If the sensor stops answering after a power change and every bus comes back
empty, it is the wiring, not the software. Check VCC is on 3.3V.

## The camera

An IMX219 module on the 22-pin 0.5 mm flex connector, contacts facing the
board. The CSI0 routing is Arduino's own, copied from the UNO Media Carrier, so
the board enumerates exactly as the carrier does.

## Speaker, distance sensor, feet

- Speaker: the 2-pin plug off the PAM8302A. 4 or 8 ohm, up to about 2.5 W.
- Distance: a VL53L5CX or VL53L8CX breakout on the 4-pin header.
- Feet: one 2-pin plug per foot, a switch or an FSR to ground. Pull-ups are on
  the board.

## Power-on order

1. UNO Q on USB-C first. Wait until the page answers on port 8938.
2. Servo supply second.
3. Check the page shows every servo you expect.

Pack first is not dangerous. It only means the servos sit powered with nothing
talking to them.

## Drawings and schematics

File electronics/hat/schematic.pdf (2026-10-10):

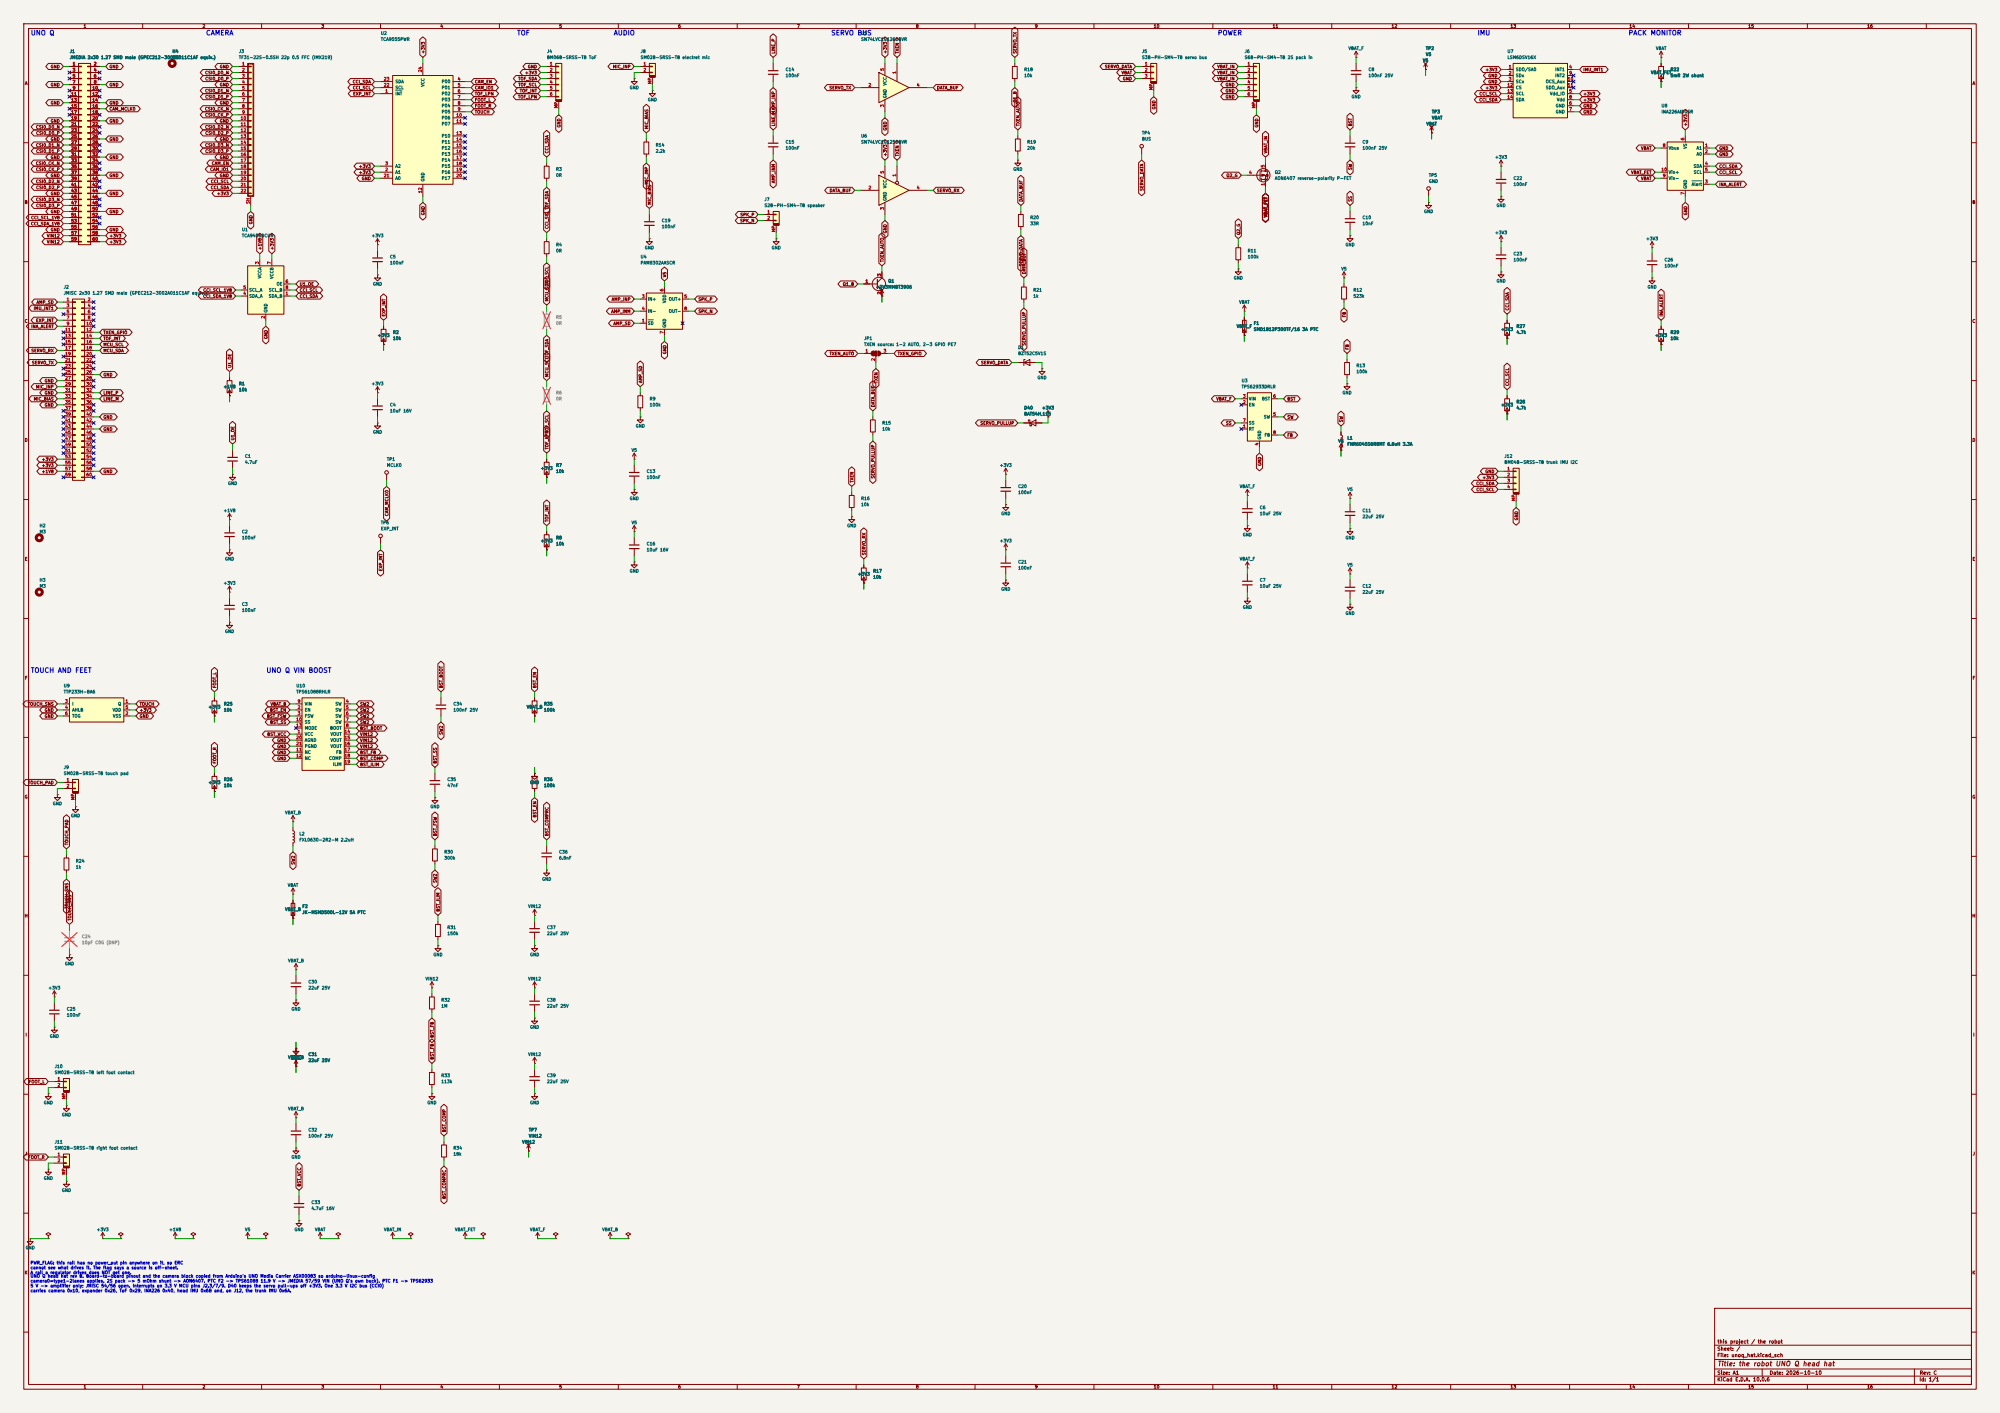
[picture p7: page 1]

JMEDIA 2x30 1.27 SMD male (GPEC212-3002A011C1AF equiv.)

SM02B-SRSS-TB electret mic GND

JMISC 2x30 1.27 SMD male (GPEC212-3002A011C1AF equiv.)

SM02B-SRSS-TB touch pad GND
GND +3V3 GND

SM02B-SRSS-TB left foot contact

SM02B-SRSS-TB right foot contact GND

5 V -> amplifier only; JMISC 54/56 open. Interrupts on 3.3 V MCU pins J2.3/7/9. D40 keeps the servo pull-ups off +3V3. One 3.3 V I2C bus (CCI0) carries camera 0x10, expander 0x26, ToF 0x29, INA226 0x40, head IMU 0x6B and, on J12, the trunk IMU 0x6A. PWR_FLAG: this rail has no power_out pin anywhere on it, so ERC
cannot see what drives it. The flag says a source is off-sheet. A rail a regulator drives does NOT get one.

UNO Q head hat rev B. Board-to-board pinout and the camera block copied from Arduino's UNO Media Carrier ASX00083 so arduino-linux-config
camera0=type1-2lanes applies. 2S pack -> 5 mOhm shunt -> AON6407. PTC F2 -> TPS61088 11.9 V -> JMEDIA 57/59 VIN (UNO Q's own buck). PTC F1 -> TPS62933

this project / the robot
Sheet: /
File: unoq_hat.kicad_sch
Title: the robot UNO Q head hat

Size: A1 | Rev: C
KiCad E.D.A. 10.0.6 | Id: 1/1

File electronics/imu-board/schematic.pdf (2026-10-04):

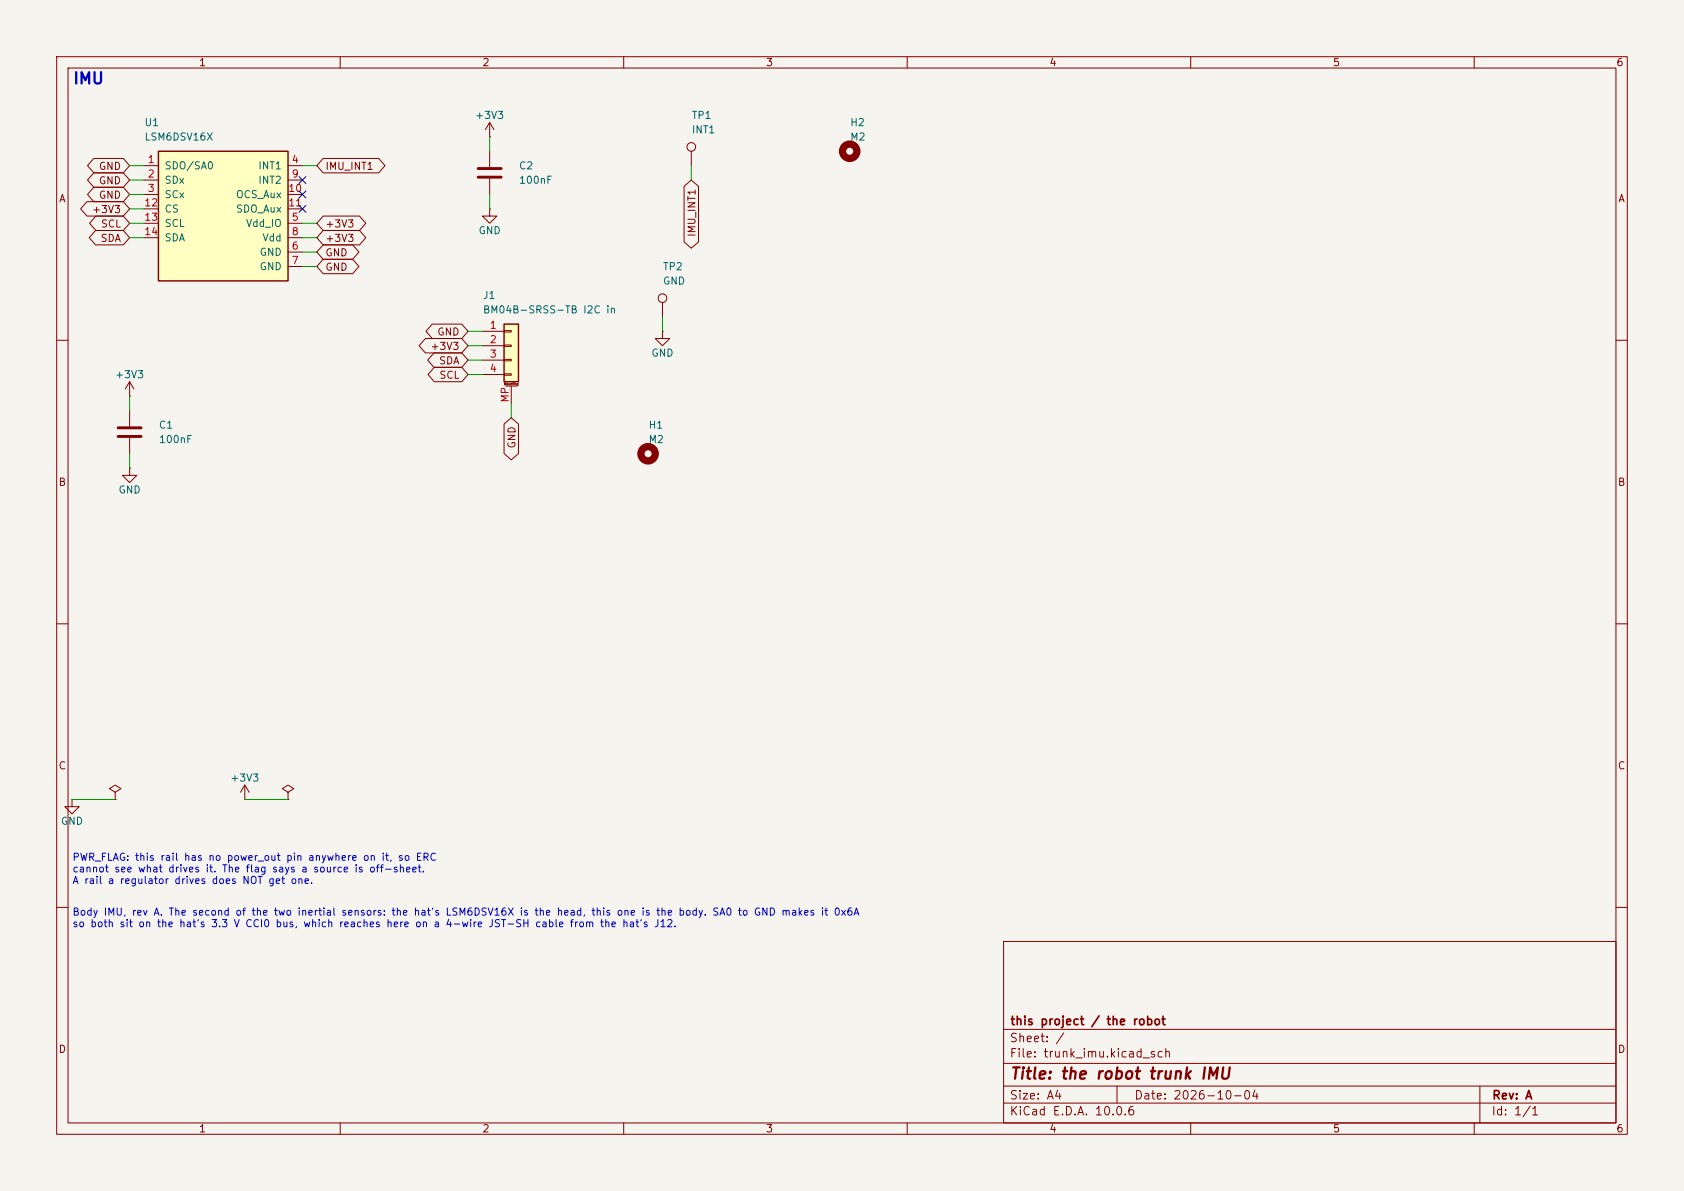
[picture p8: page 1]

PWR_FLAG: this rail has no power_out pin anywhere on it, so ERC
cannot see what drives it. The flag says a source is off-sheet. A rail a regulator drives does NOT get one. Body IMU, rev A. The second of the two inertial sensors: the hat's LSM6DSV16X is the head, this one is the body. SA0 to GND makes it 0x6A

so both sit on the hat's 3.3 V CCI0 bus, which reaches here on a 4-wire JST-SH cable from the hat's J12.

this project / the robot
Sheet: /
File: trunk_imu.kicad_sch
Title: the robot trunk IMU

Size: A4 | Rev: A
KiCad E.D.A. 10.0.6 | Id: 1/1

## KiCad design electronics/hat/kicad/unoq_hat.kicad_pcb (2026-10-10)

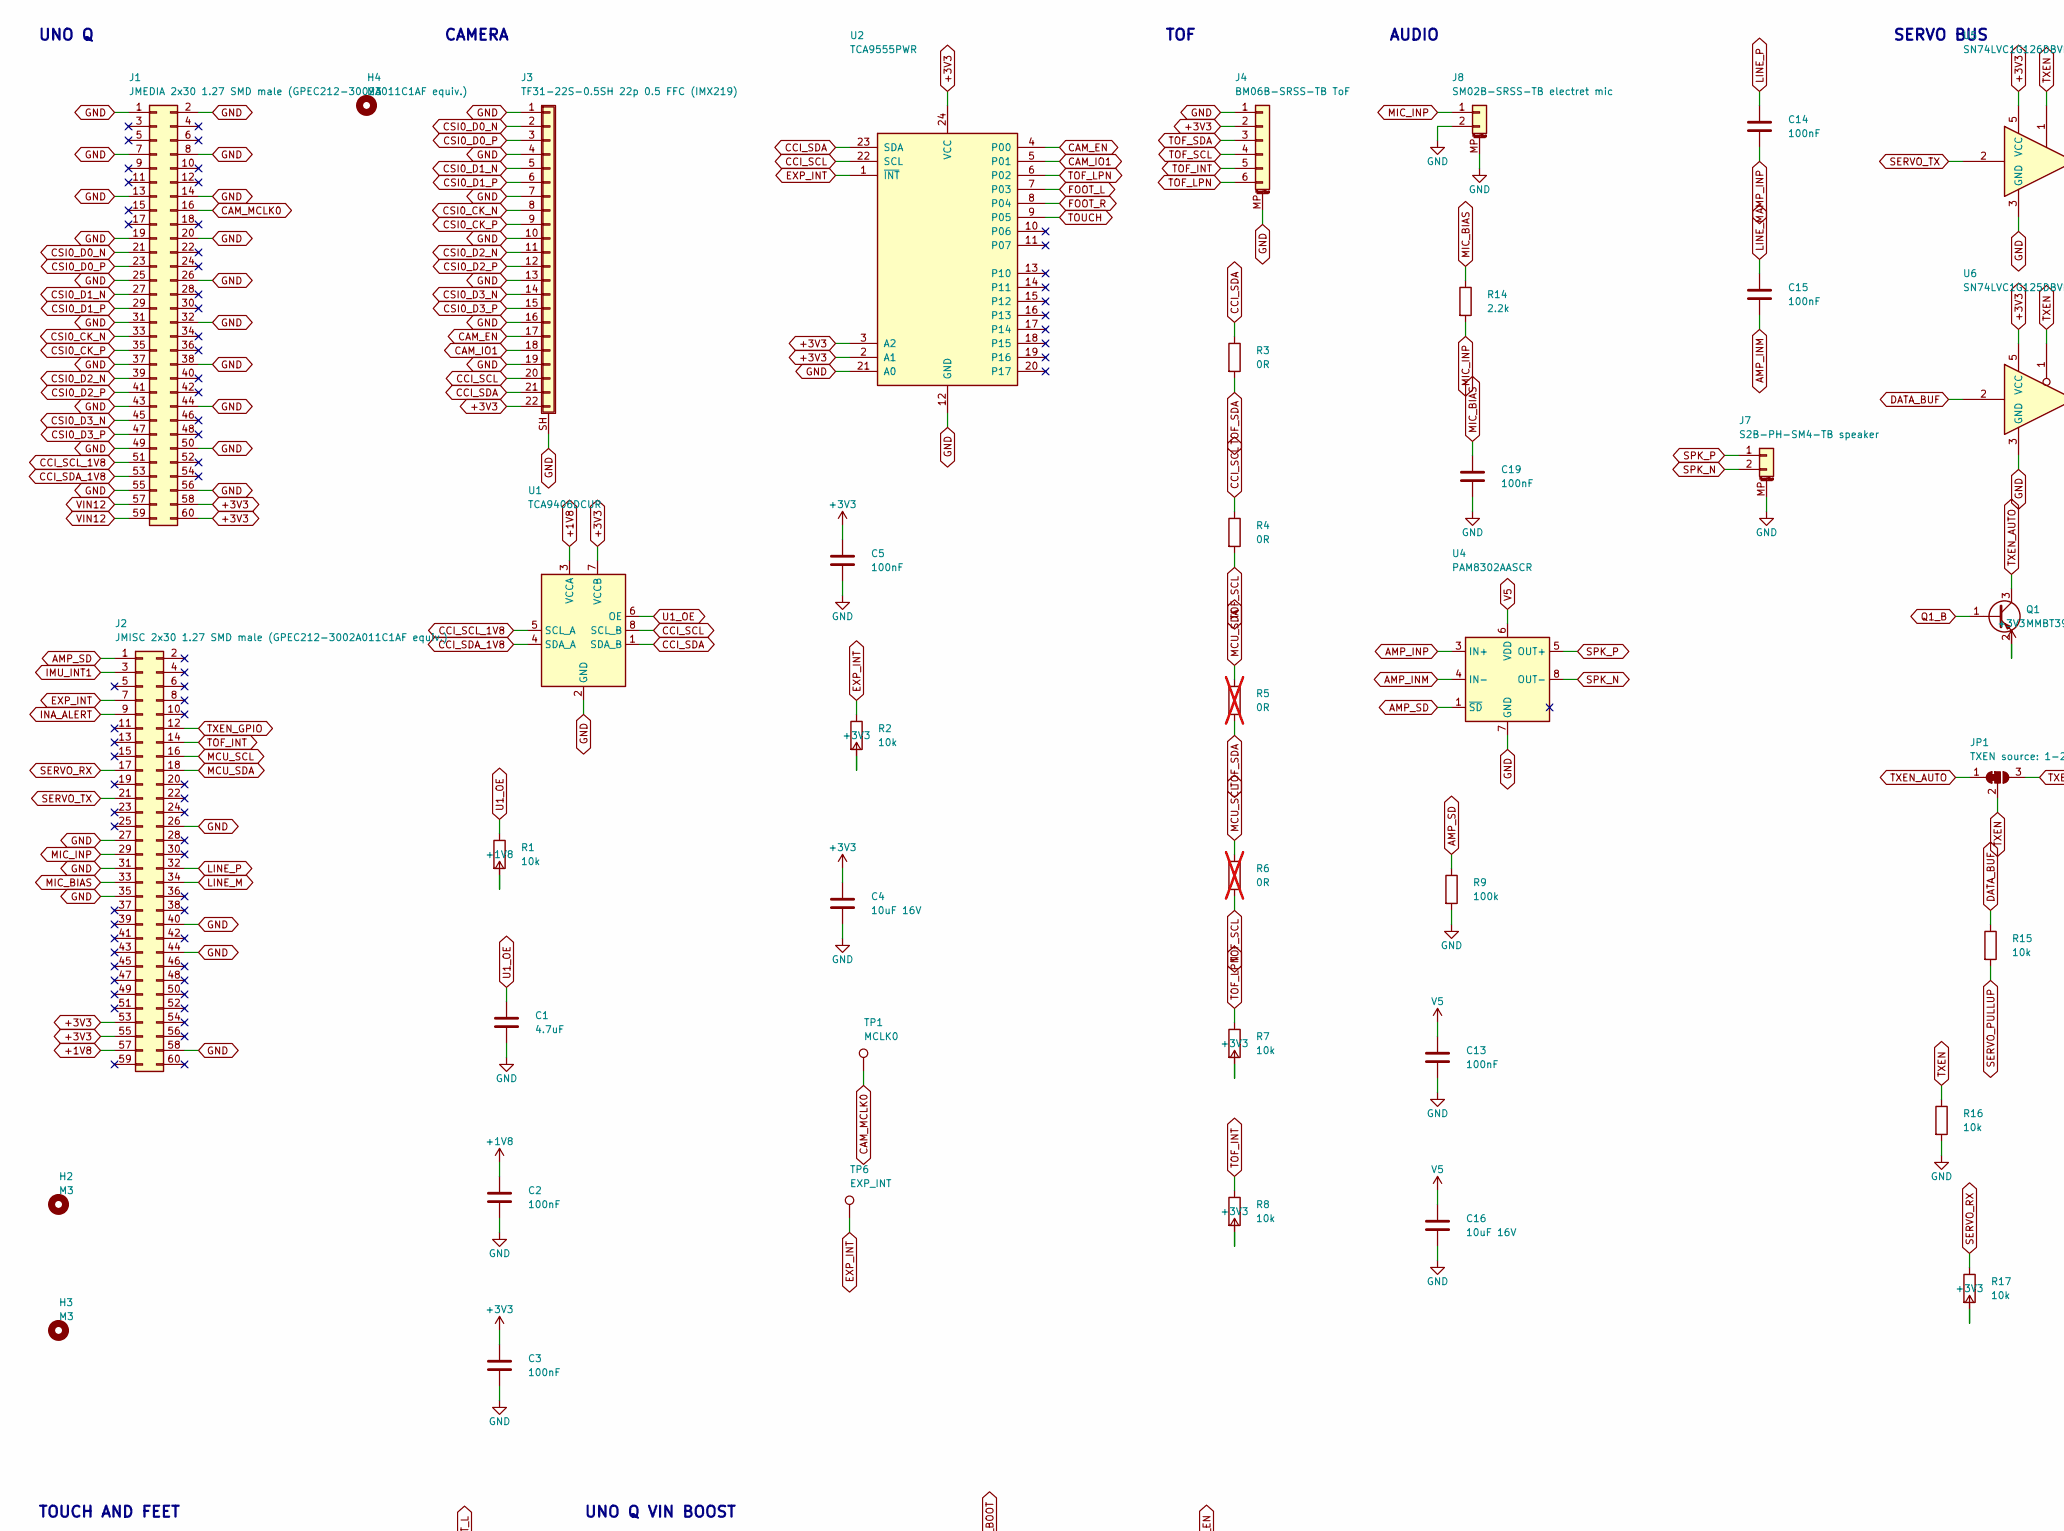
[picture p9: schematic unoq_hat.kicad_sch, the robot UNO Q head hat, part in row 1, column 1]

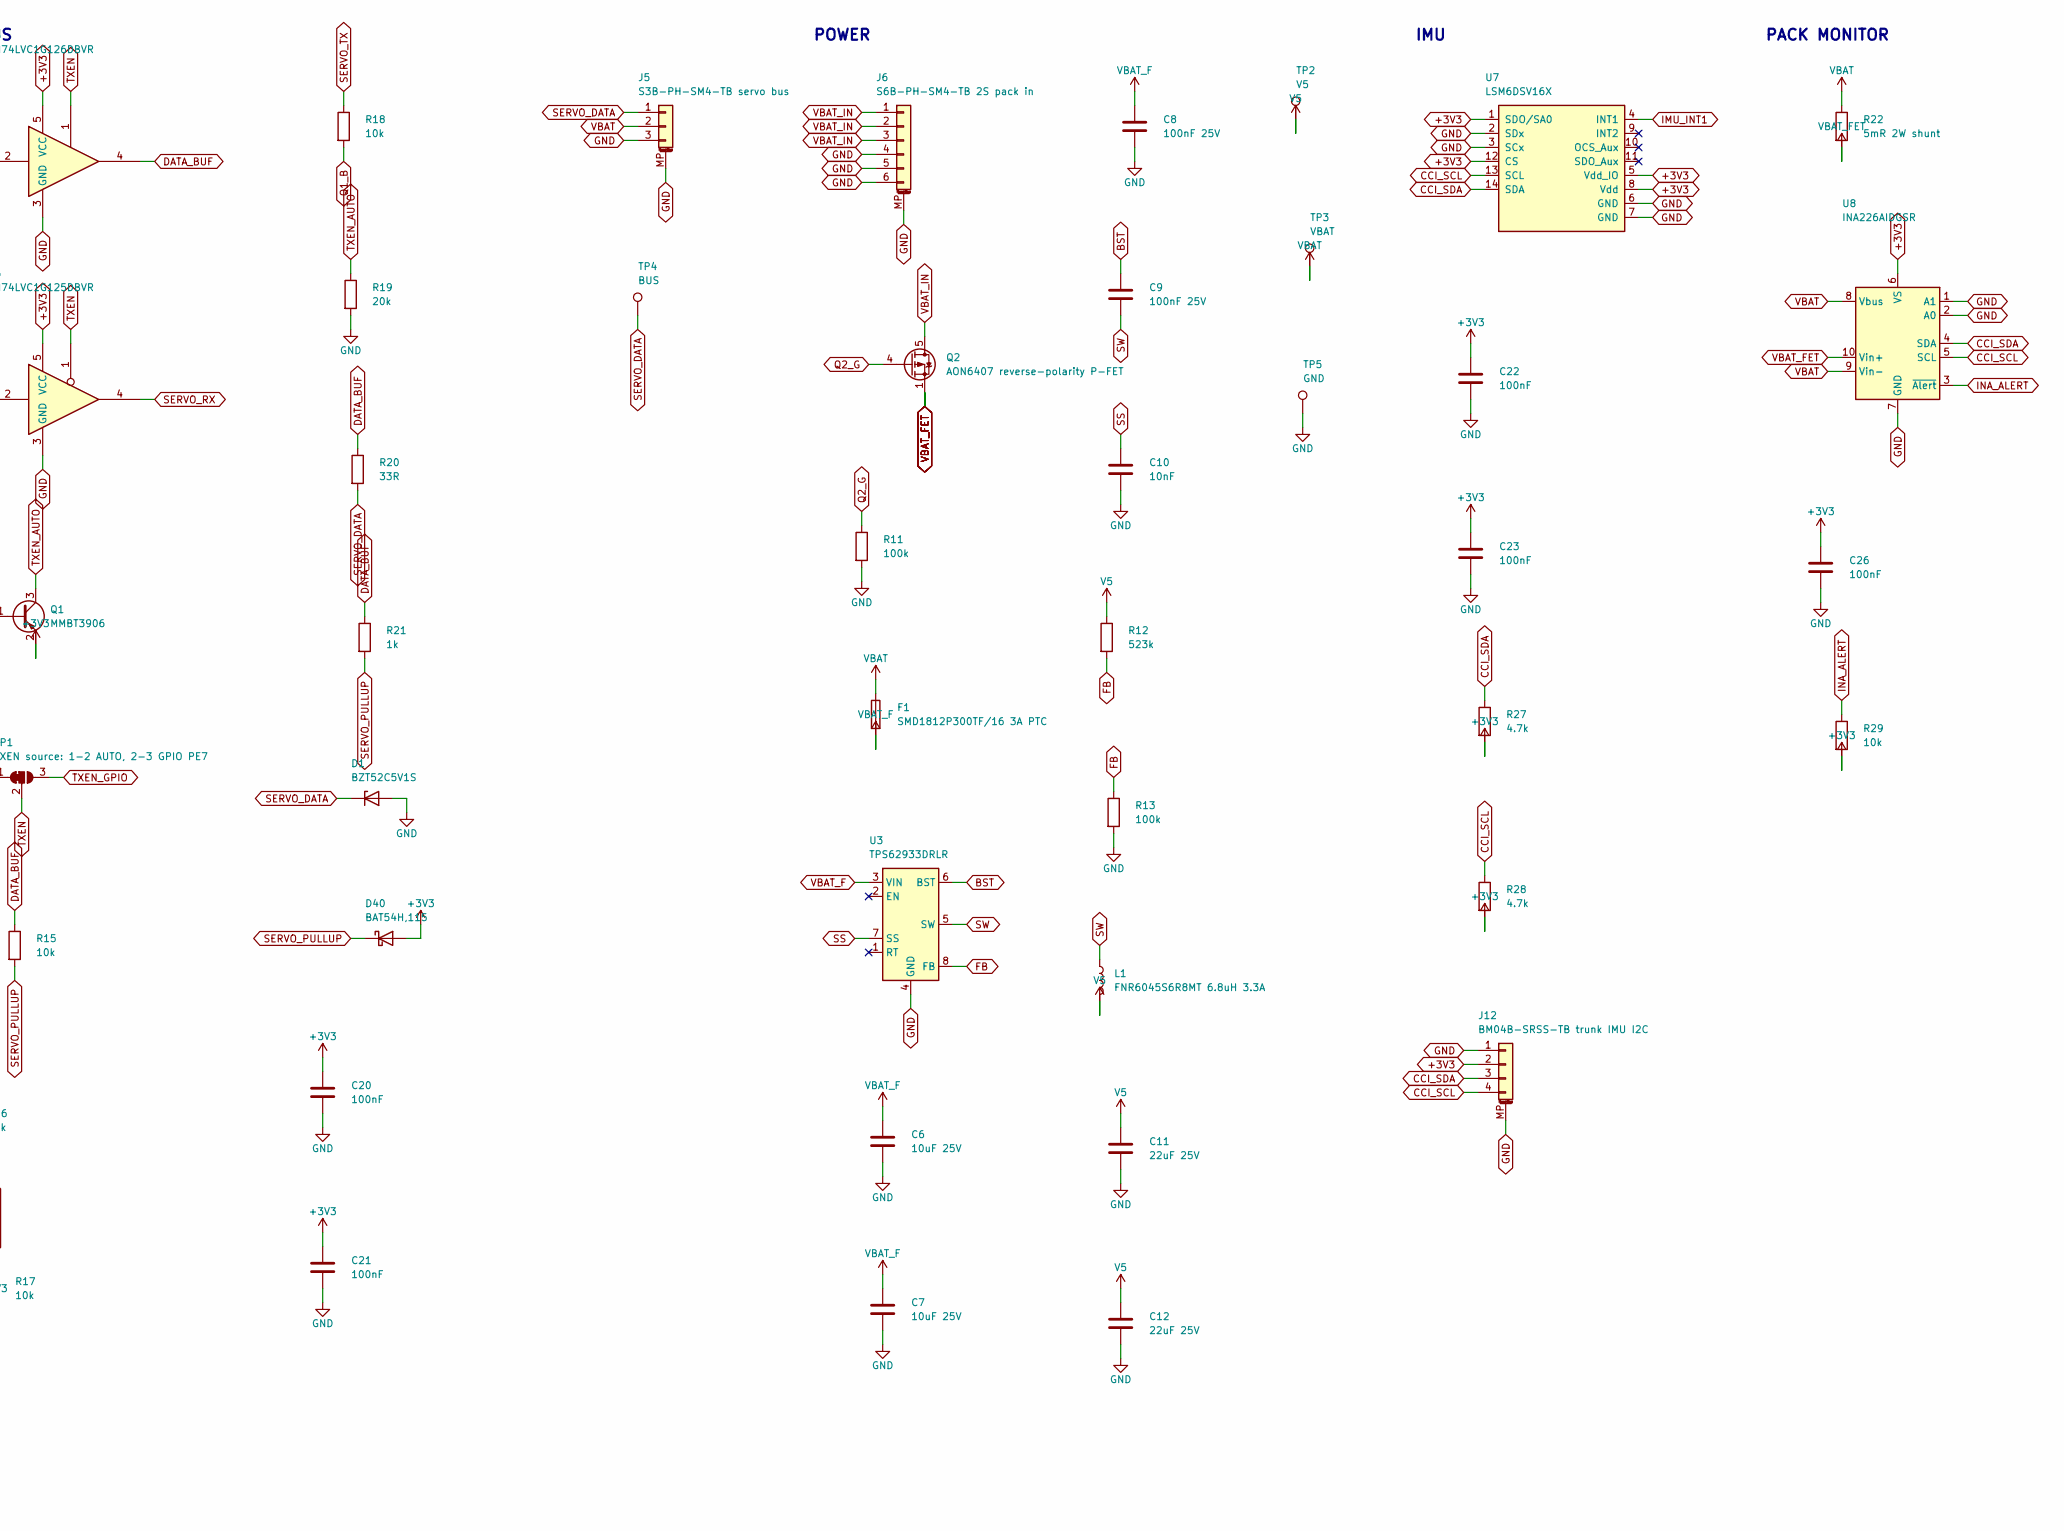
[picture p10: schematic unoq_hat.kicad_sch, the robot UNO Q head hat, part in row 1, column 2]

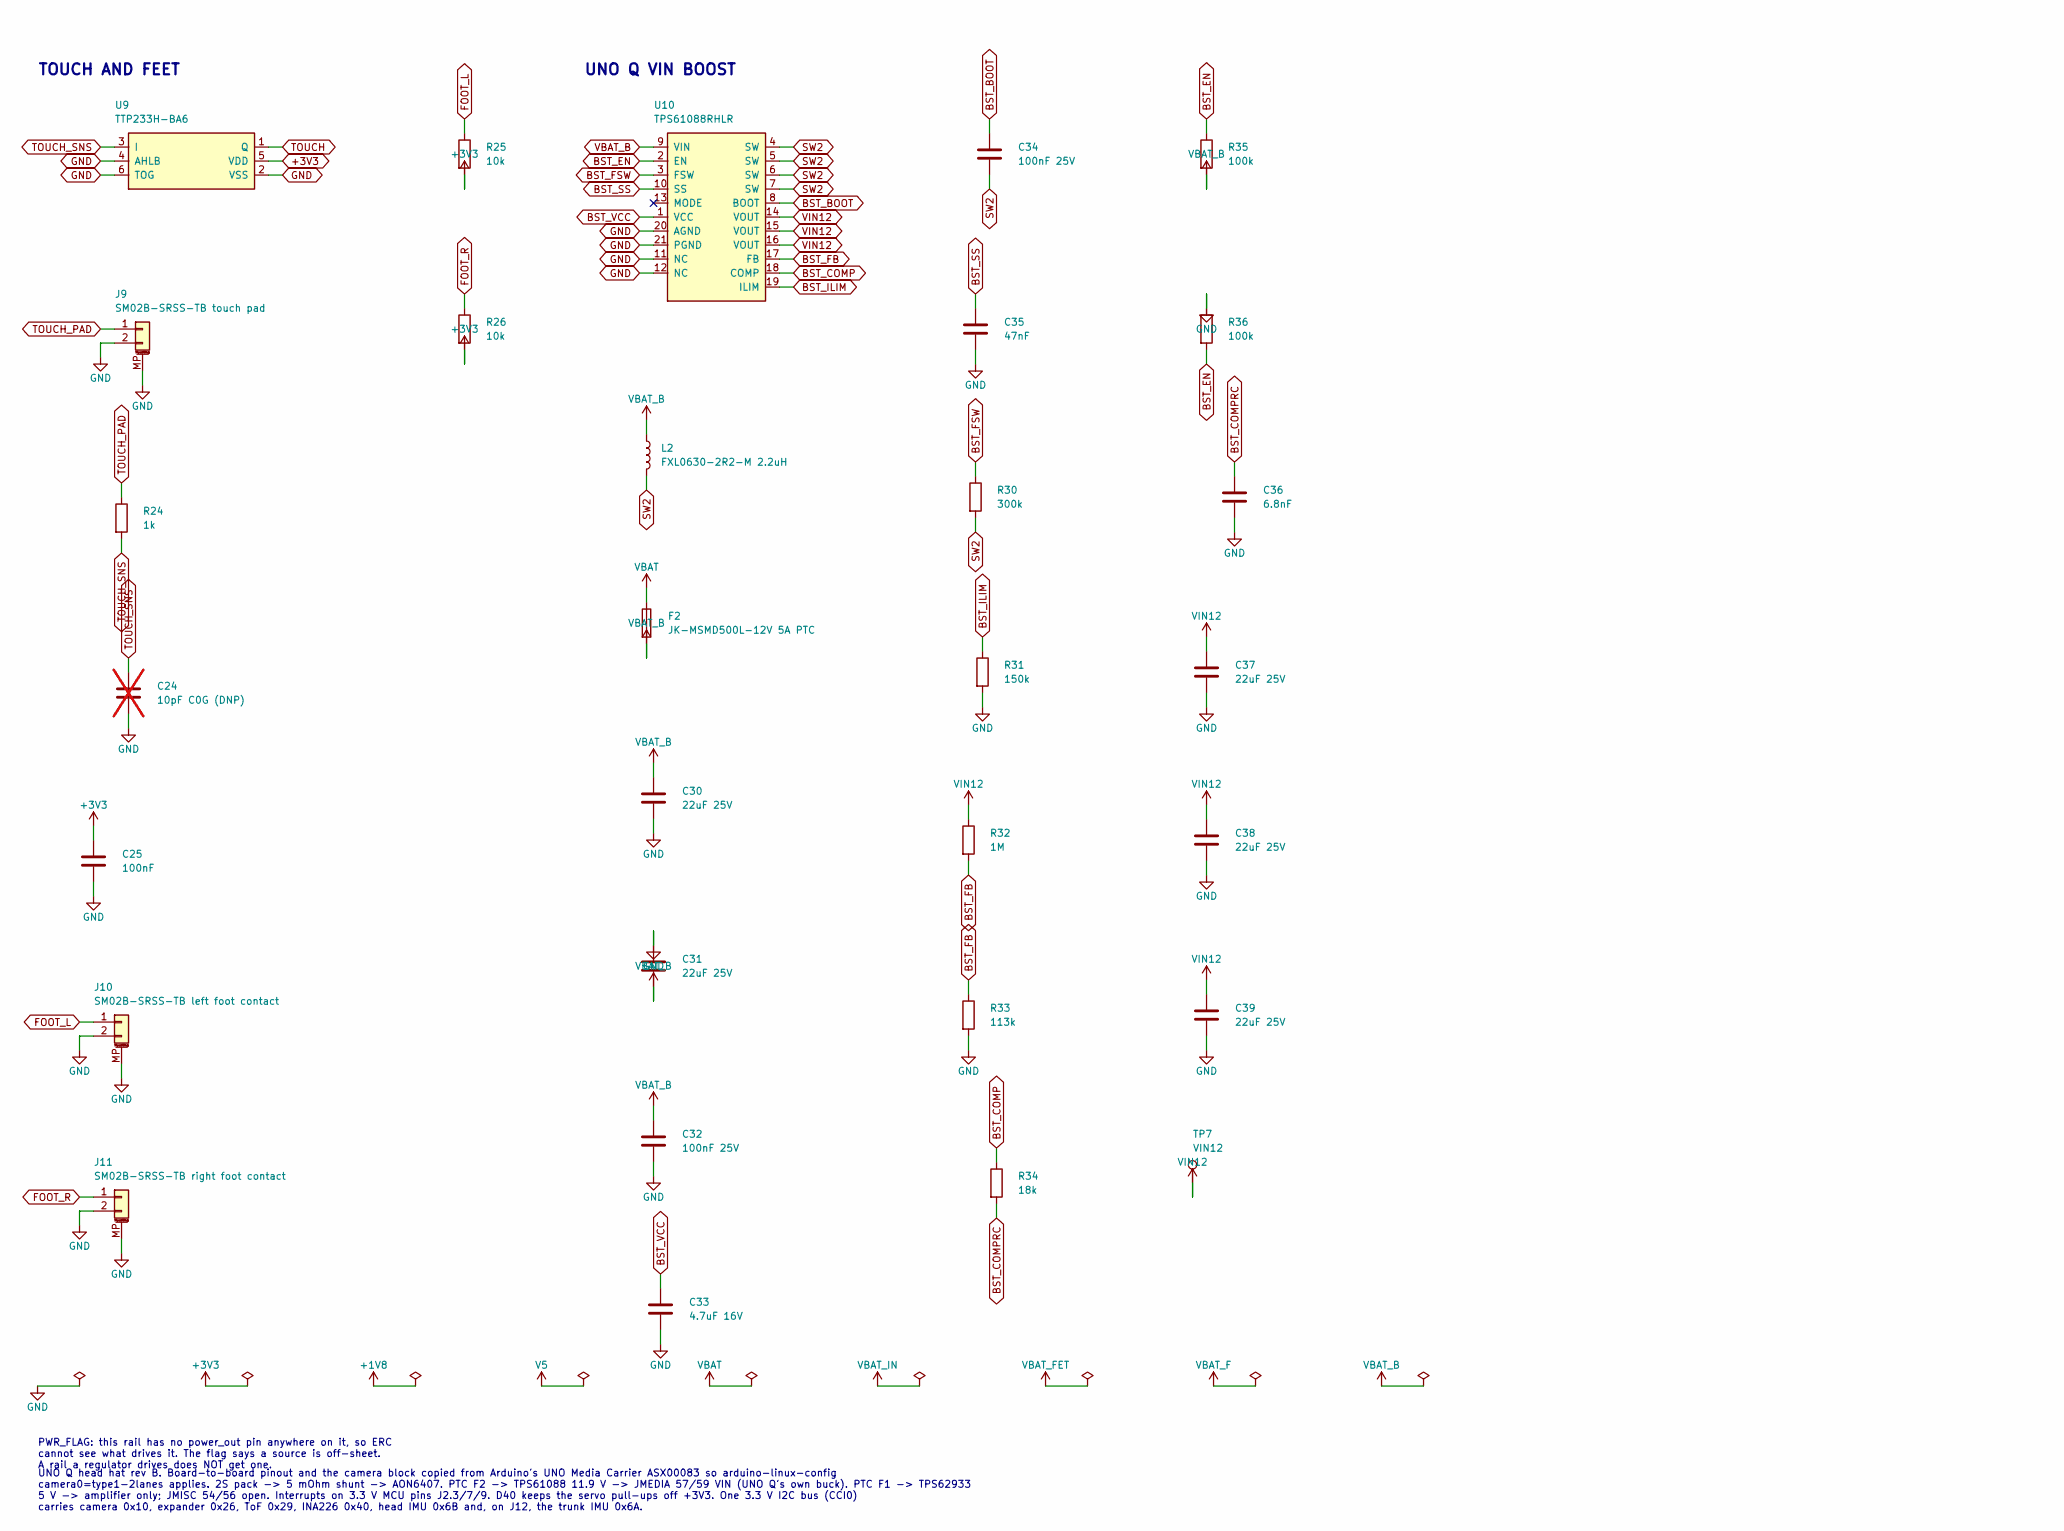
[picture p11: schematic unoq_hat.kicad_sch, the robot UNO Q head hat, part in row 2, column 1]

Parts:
C1: 4.7uF; C_0402_1005Metric; LCSC Part # C23733
C2, C3, C5, C13, C14, C15, C19, C20, C21, C22, C23, C25, C26: 100nF; C_0402_1005Metric; LCSC Part # C1525
C4, C16: 10uF 16V; C_0805_2012Metric; LCSC Part # C1713
C6, C7: 10uF 25V; C_1206_3216Metric; LCSC Part # C77090
C8, C9, C32, C34: 100nF 25V; C_0402_1005Metric; LCSC Part # C105883
C10: 10nF; C_0402_1005Metric; LCSC Part # C60133
C11, C12, C30, C31, C37, C38, C39: 22uF 25V; C_1210_3225Metric; LCSC Part # C52306
C24: 10pF C0G (DNP); C_0402_1005Metric; not fitted
C33: 4.7uF 16V; C_0603_1608Metric; LCSC Part # C19666
C35: 47nF; C_0402_1005Metric; LCSC Part # C82219
C36: 6.8nF; C_0402_1005Metric; LCSC Part # C1542
D1: BZT52C5V1S; D_SOD-323; LCSC Part # C151348
D40: BAT54H,115; BAT54H_Nexperia_SOD123F; LCSC Part # C426769
F1: SMD1812P300TF/16 3A PTC; Fuse_1812_4532Metric; LCSC Part # C702820
F2: JK-MSMD500L-12V 5A PTC; Fuse_1812_4532Metric; LCSC Part # C2844238
H2, H3, H4: M3; MountingHole_3.2mm_M3
J1: JMEDIA 2x30 1.27 SMD male (GPEC212-3002A011C1AF e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; UNOQ_JMEDIA_2x30_P1.27_Male; LCSC Part # C191721
J2: JMISC 2x30 1.27 SMD male (GPEC212-3002A011C1AF eq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; UNOQ_JMEDIA_2x30_P1.27_Male; LCSC Part # C191721
J3: TF31-22S-0.5SH 22p 0.5 FFC (IMX219); FFC_22P_P0.5_TF31-22S; LCSC Part # C3169786
J4: BM06B-SRSS-TB ToF; JST_SH_BM06B-SRSS-TB_1x06-1MP_P1.00mm_Vertical; LCSC Part # C160392
J5: S3B-PH-SM4-TB servo bus; JST_PH_S3B-PH-SM4-TB_1x03-1MP_P2.00mm_Horizontal; LCSC Part # C265101
J6: S6B-PH-SM4-TB 2S pack in; JST_PH_S6B-PH-SM4-TB_1x06-1MP_P2.00mm_Horizontal; LCSC Part # C265405
J7: S2B-PH-SM4-TB speaker; JST_PH_S2B-PH-SM4-TB_1x02-1MP_P2.00mm_Horizontal; LCSC Part # C295747
J8: SM02B-SRSS-TB electret mic; JST_SH_SM02B-SRSS-TB_1x02-1MP_P1.00mm_Horizontal; LCSC Part # C160402
J9: SM02B-SRSS-TB touch pad; JST_SH_SM02B-SRSS-TB_1x02-1MP_P1.00mm_Horizontal; LCSC Part # C160402
J10: SM02B-SRSS-TB left foot contact; JST_SH_SM02B-SRSS-TB_1x02-1MP_P1.00mm_Horizontal; LCSC Part # C160402
J11: SM02B-SRSS-TB right foot contact; JST_SH_SM02B-SRSS-TB_1x02-1MP_P1.00mm_Horizontal; LCSC Part # C160402
J12: BM04B-SRSS-TB trunk IMU I2C; JST_SH_BM04B-SRSS-TB_1x04-1MP_P1.00mm_Vertical; LCSC Part # C160390
JP1: TXEN source: 1-2 AUTO, 2-3 GPIO PE7; SolderJumper-3_P1.3mm_Bridged12_RoundedPad1.0x1.5mm
L1: FNR6045S6R8MT 6.8uH 3.3A; FNR6045_6.0x6.0mm; LCSC Part # C168072
L2: FXL0630-2R2-M 2.2uH; L_Changjiang_FXL0630; LCSC Part # C167218
Q1: MMBT3906; SOT-23; LCSC Part # C727128
Q2: AON6407 reverse-polarity P-FET; PowerPAK_SO-8_Single; LCSC Part # C13899
R1, R2, R7, R8, R15, R16, R17, R18, R25, R26, R29: 10k; R_0402_1005Metric; LCSC Part # C25744
R3, R4: 0R; R_0402_1005Metric; LCSC Part # C17168
R5, R6: 0R; R_0402_1005Metric; LCSC Part # C17168; not fitted
R9, R11, R13, R35, R36: 100k; R_0402_1005Metric; LCSC Part # C25741
R12: 523k; R_0402_1005Metric; LCSC Part # C27011
R14: 2.2k; R_0402_1005Metric; LCSC Part # C25879
R19: 20k; R_0402_1005Metric; LCSC Part # C25765
R20: 33R; R_0402_1005Metric; LCSC Part # C138002
R21, R24: 1k; R_0402_1005Metric; LCSC Part # C106235
R22: 5mR 2W shunt; R_2512_6332Metric; LCSC Part # C185817
R27, R28: 4.7k; R_0402_1005Metric; LCSC Part # C25900
R30: 300k; R_0402_1005Metric; LCSC Part # C25774
R31: 150k; R_0402_1005Metric; LCSC Part # C25755
R32: 1M; R_0402_1005Metric; LCSC Part # C26083
R33: 113k; R_0402_1005Metric; LCSC Part # C25746
R34: 18k; R_0402_1005Metric; LCSC Part # C25762
TP1: MCLK0; TestPoint_Pad_D1.0mm
TP2: V5; TestPoint_Pad_D1.0mm
TP3: VBAT; TestPoint_Pad_D1.0mm
TP4: BUS; TestPoint_Pad_D1.0mm
TP5: GND; TestPoint_Pad_D1.0mm
TP6: EXP_INT; TestPoint_Pad_D1.0mm
TP7: VIN12; TestPoint_Pad_D1.0mm
U1: TCA9406DCUR; VSSOP-8_2.3x2mm_P0.5mm; LCSC Part # C840107
U2: TCA9555PWR; TSSOP-24_4.4x7.8mm_P0.65mm; LCSC Part # C465732
U3: TPS62933DRLR; SOT-583-8; LCSC Part # C3200405
U4: PAM8302AASCR; MSOP-8_3x3mm_P0.65mm; LCSC Part # C113367
U5: SN74LVC1G126DBVR; SOT-23-5; LCSC Part # C7834
U6: SN74LVC1G125DBVR; SOT-23-5; LCSC Part # C23654
U7: LSM6DSV16X; LGA-14_3x2.5mm_P0.5mm_LayoutBorder3x4y; LCSC Part # C5267406
U8: INA226AIDGSR; TSSOP-10_3x3mm_P0.5mm; LCSC Part # C49851
U9: TTP233H-BA6; SOT-23-6; LCSC Part # C2890349
U10: TPS61088RHLR; Texas_VQFN-RHL-20; LCSC Part # C87357

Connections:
AMP_INM: C15.2, U4.4 (IN-)
AMP_INP: C14.2, U4.3 (IN+)
AMP_SD: J2.1, R9.1, U4.1 (~SD)
BST: C9.1, U3.6 (BST)
BST_BOOT: C34.1, U10.8 (BOOT)
BST_COMP: R34.1, U10.18 (COMP)
BST_COMPRC: C36.1, R34.2
BST_EN: R35.1, R36.2, U10.2 (EN)
BST_FB: R32.2, R33.1, U10.17 (FB)
BST_FSW: R30.1, U10.3 (FSW)
BST_ILIM: R31.1, U10.19 (ILIM)
BST_SS: C35.1, U10.10 (SS)
BST_VCC: C33.1, U10.1 (VCC)
CAM_EN: J3.17, U2.4 (P00)
CAM_IO1: J3.18, U2.5 (P01)
CAM_MCLK0: J1.16, TP1.1
CCI_SCL: J3.20, J12.4, R4.1, R28.1, U1.8 (SCL_B), U2.22 (SCL), U7.13 (SCL), U8.5 (SCL)
CCI_SCL_1V8: J1.51, U1.5 (SCL_A)
CCI_SDA: J3.21, J12.3, R3.1, R27.1, U1.1 (SDA_B), U2.23 (SDA), U7.14 (SDA), U8.4 (SDA)
CCI_SDA_1V8: J1.53, U1.4 (SDA_A)
CSI0_CK_N: J1.33, J3.8
CSI0_CK_P: J1.35, J3.9
CSI0_D0_N: J1.21, J3.2
CSI0_D0_P: J1.23, J3.3
CSI0_D1_N: J1.27, J3.5
CSI0_D1_P: J1.29, J3.6
CSI0_D2_N: J1.39, J3.11
CSI0_D2_P: J1.41, J3.12
CSI0_D3_N: J1.45, J3.14
CSI0_D3_P: J1.47, J3.15
DATA_BUF: R15.1, R20.1, R21.1, U5.4, U6.2
EXP_INT: J2.7, R2.1, TP6.1, U2.1 (~INT)
FB: R12.2, R13.1, U3.8 (FB)
FOOT_L: J10.1, R25.1, U2.7 (P03)
FOOT_R: J11.1, R26.1, U2.8 (P04)
IMU_INT1: J2.3, U7.4 (INT1)
INA_ALERT: J2.9, R29.1, U8.3 (~Alert)
LINE_M: C15.1, J2.34
LINE_P: C14.1, J2.32
MCU_SCL: J2.16, R6.1
MCU_SDA: J2.18, R5.1
MIC_BIAS: C19.1, J2.33, R14.1
MIC_INP: J2.29, J8.1, R14.2
Q1_B: Q1.1 (B), R18.2
Q2_G: Q2.4 (G), R11.1
SERVO_DATA: D1.1 (K), J5.1, R20.2, TP4.1
SERVO_PULLUP: D40.1 (K), R15.2, R21.2
SERVO_RX: J2.17, R17.1, U6.4
SERVO_TX: J2.21, R18.1, U5.2
SPK_N: J7.2, U4.8 (OUT-)
SPK_P: J7.1, U4.5 (OUT+)
SS: C10.1, U3.7 (SS)
SW: C9.2, L1.1, U3.5 (SW)
SW2: C34.2, L2.2, R30.2, U10.4 (SW), U10.5 (SW), U10.6 (SW), U10.7 (SW)
TOF_INT: J2.14, J4.5, R8.1
TOF_LPN: J4.6, R7.1, U2.6 (P02)
TOF_SCL: J4.4, R4.2, R6.2
TOF_SDA: J4.3, R3.2, R5.2
TOUCH: U2.9 (P05), U9.1 (Q)
TOUCH_PAD: J9.1, R24.1
TOUCH_SNS: C24.1, R24.2, U9.3 (I)
TXEN: JP1.2 (C), R16.1, U5.1, U6.1
TXEN_AUTO: JP1.1 (A), Q1.3 (C), R19.1
TXEN_GPIO: J2.12, JP1.3 (B)
U1_OE: C1.1, R1.1, U1.6 (OE)
VBAT_IN: J6.1, J6.2, J6.3, Q2.5 (D)
VIN12: C37.1, C38.1, C39.1, J1.57, J1.59, R32.1, TP7.1, U10.14 (VOUT), U10.15 (VOUT), U10.16 (VOUT)

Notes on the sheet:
UNO Q
CAMERA
TOF
AUDIO
SERVO BUS
POWER
IMU
PACK MONITOR
TOUCH AND FEET
UNO Q VIN BOOST
PWR_FLAG: this rail has no power_out pin anywhere on it, so ERC cannot see what drives it. The flag says a source is off-sheet. A rail a regulator drives does NOT get one.
UNO Q head hat rev B. Board-to-board pinout and the camera block copied from Arduino's UNO Media Carrier ASX00083 so arduino-linux-config camera0=type1-2lanes applies. 2S pack -> 5 mOhm shunt -> AON6407. PTC F2 -> TPS61088 11.9 V -> JMEDIA 57/59 VIN (UNO Q's own buck). PTC F1 -> TPS62933 5 V -> amp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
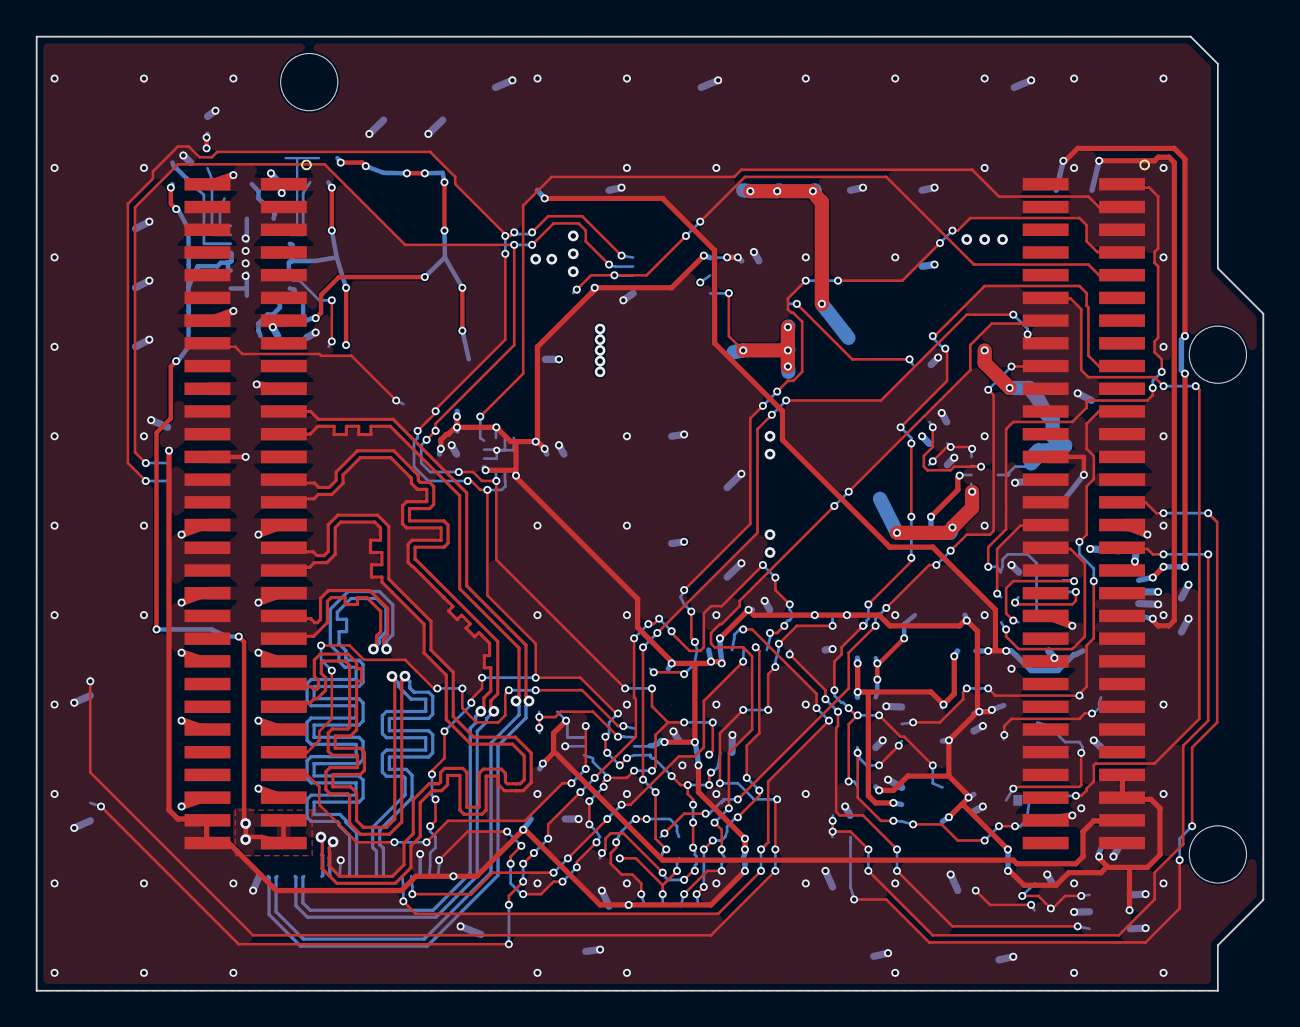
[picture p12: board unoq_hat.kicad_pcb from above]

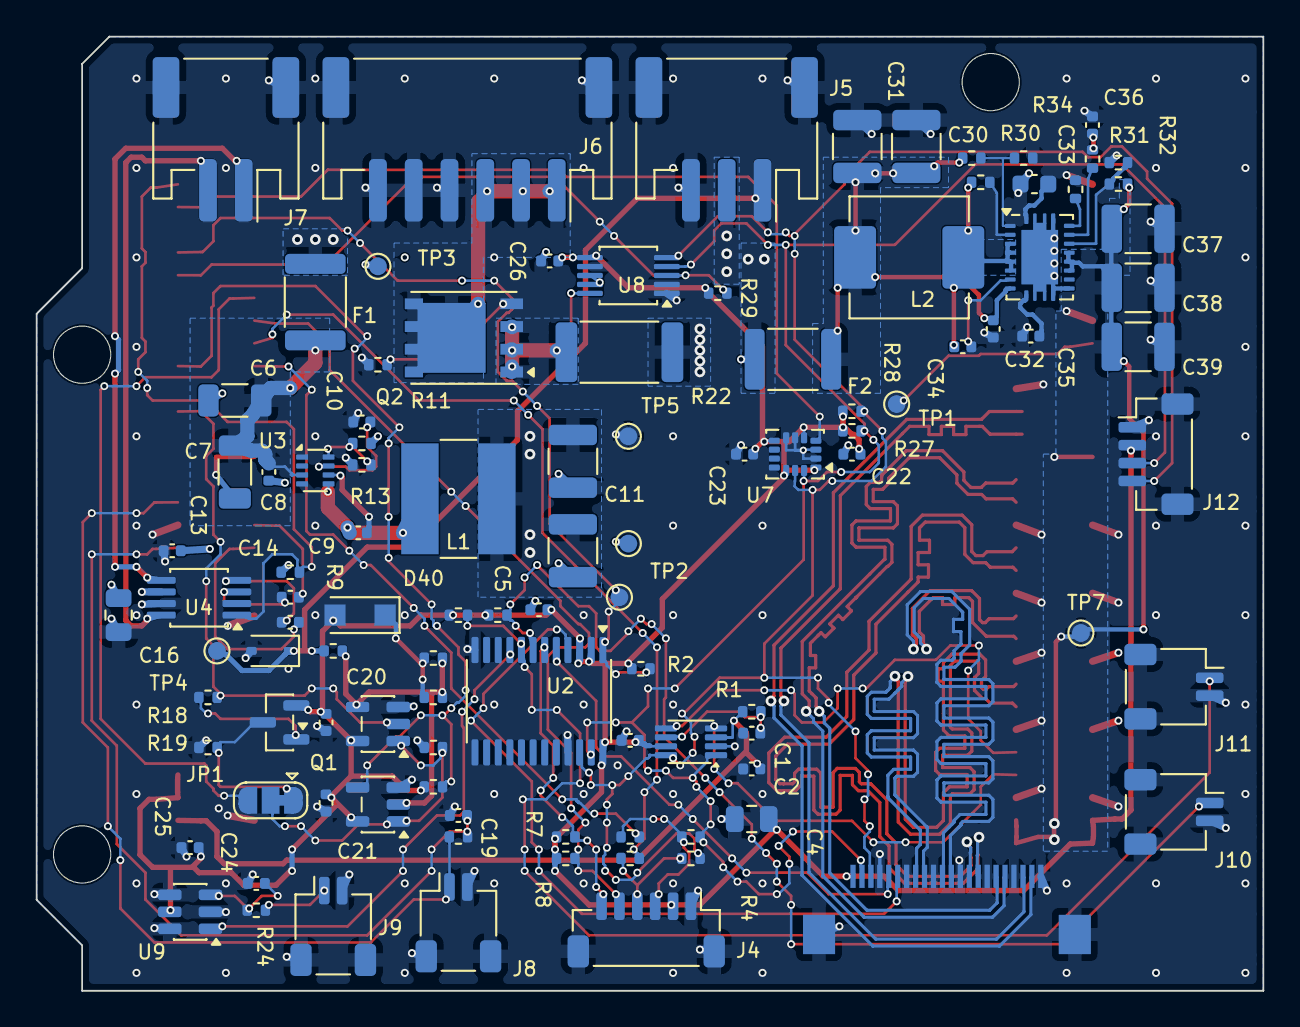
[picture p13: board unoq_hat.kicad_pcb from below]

Board: 4 copper layers, 68.6 x 53.3 mm, 109 parts (104 on the bottom side), 75 nets.

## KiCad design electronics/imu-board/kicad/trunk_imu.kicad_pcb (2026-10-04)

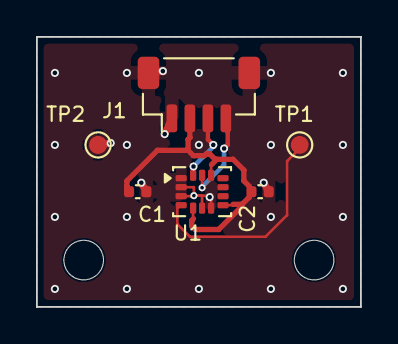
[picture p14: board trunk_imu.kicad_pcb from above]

Board: 2 copper layers, 18.0 x 15.0 mm, 8 parts (0 on the bottom side), 5 nets.

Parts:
C1, C2: 100nF; C_0402_1005Metric
H1, H2: M2; MountingHole_2.2mm_M2
J1: BM04B-SRSS-TB I2C in; JST_SH_BM04B-SRSS-TB_1x04-1MP_P1.00mm_Vertical
TP1: INT1; TestPoint_Pad_D1.0mm
TP2: GND; TestPoint_Pad_D1.0mm
U1: LSM6DSV16X; LGA-14_3x2.5mm_P0.5mm_LayoutBorder3x4y

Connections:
+3V3: C1.1, C2.1, J1.2, U1.5, U1.8, U1.12
GND: C1.2, C2.2, J1.1, J1.MP, TP2.1, U1.1, U1.2, U1.3, U1.6, U1.7
IMU_INT1: TP1.1, U1.4
SCL: J1.4, U1.13
SDA: J1.3, U1.14

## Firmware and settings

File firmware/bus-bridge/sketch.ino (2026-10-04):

// servo-bus MCU half (Uno Q app `servo-bus-bridge`).
// Raw packet pass-through to a Feetech-style TTL servo bus on D0/D1 (Serial1) via a URT-2.
// The sketch knows frame boundaries and nothing else: the Linux side (the Rust daemon)
// builds every packet and parses every reply, so the register map lives in one place.
//
// bus_batch is the fast path. One RouterBridge call (~7 ms round trip, measured 2026-10-02)
// carries many bus transactions, and each one returns as soon as its expected byte count
// is in, instead of one RPC per received byte (bus_rx), which cost ~27 calls per read.
//
//   in : frames = [expect, FF FF id len inst params.. chk] repeated; wait_us = per-frame cap
//   out: [n, n received bytes] per frame, echo included (the URT-2 hears its own TX)
//
// bus_begin / bus_send / bus_rx / bus_baud are kept so bus.py and servo_live.py still work.
//
// imu_scan / imu_begin / imu_read / imu_stats read an MPU-6050 on whichever I2C bus it is wired to
// (header D20/D21 = Wire, Qwiic = Wire1), because the walking policy needs a gyro and a gravity
// direction and nothing else on the robot has one.
//
//
// Also drives the board's 13 x 8 LED matrix (3 grayscale bits, 0..7) and the RGB LED3, so the leg's
// live stats can show while it walks 07 "use the aurdino led matrix as a output
// device for me to see statistics"). The MCU runs one sketch at a time, so the matrix lives here;
// mx_* and set_led3_color are byte-compatible with the unoq-matrix app.
#include <vector>
#include <utility>
#include <zephyr/kernel.h>
#include <zephyr/sys/atomic.h>
#include <Arduino_RPClite.h>
// Arduino_RouterBridge 0.4.3 runs every RPC handler on a thread with a 500-byte stack (UPDATE_THREAD_STACK_SIZE,
// no #ifndef) and puts a 256-byte RPCRequest plus packer and unpacker on it. The MCU wedged every 30 s - 3 min
// on 2026-10-04 (15:53-16:06) with every method dead, bus_baud and led3_state included. We reach the private
// thread id to stop that thread and run Bridge.update() on our own 8 KB stack instead (see setup()).
#include <Arduino_RouterBridge.h>
#include <Arduino_LED_Matrix.h>
#include <Wire.h>
// Reading the private BridgeClass::upd_tid: an explicit template instantiation may name a private member.
template <typename Tag, typename Tag::type M> struct Rob { friend typename Tag::type get(Tag) { return M; } };
struct UpdTid { typedef k_tid_t BridgeClass::*type; friend type get(UpdTid); };
template struct Rob<UpdTid, &BridgeClass::upd_tid>;
struct ReadMx { typedef struct k_mutex BridgeClass::*type; friend type get(ReadMx); };
template struct Rob<ReadMx, &BridgeClass::read_mutex>;
struct WriteMx { typedef struct k_mutex BridgeClass::*type; friend type get(WriteMx); };
template struct Rob<WriteMx, &BridgeClass::write_mutex>;

K_MUTEX_DEFINE(bus_mtx);
static uint8_t g_rx[64];
static int g_rxn = 0;
static int g_baud = 0;

// NOTHING ON THIS MCU MAY WAIT FOR EVER (2026-10-04 20:53:28 and 20:55:49 CST). The sketch serves RPCs one at a
// time on one thread, so a single handler that blocks takes every method down with it: both wedges that evening
// killed bus_baud and mx_shape too, and those touch no hardware at all. The one unbounded wait was
// arduino::ZephyrSerial::write (cores/arduino/zephyrSerial.cpp): it loops `while (1)` putting bytes into the TX
// ring and yielding whenever the ring is full, so a UART whose TX interrupt has stopped firing holds the caller
// for ever. Two rules now: take the bus mutex with a deadline, and never hand Serial1 more bytes than the ring
// has room for (then ring_buf_put takes them all and write() cannot loop).
#define BUS_LOCK_MS 300
static bool bus_lock() { return k_mutex_lock(&bus_mtx, K_MSEC(BUS_LOCK_MS)) == 0; }
static uint32_t g_tx_stuck = 0;   // frames refused because the TX ring would not drain
static uint32_t g_lock_lost = 0;  // calls that gave up waiting for the bus mutex

// Reopen the port: uart_configure + uart_irq_rx_enable, which is the only cure the sketch has for a UART that
// stopped transmitting, short of the Linux side restarting the app.
static void bus_reopen() {
  if (!g_baud) return;
  Serial1.end();
  Serial1.begin((unsigned long)g_baud);
}

// Write one whole frame or none of it, never blocking. Returns false when the TX ring has no room, which means
// the UART is not draining; the port is reopened and the caller reports the frame as unsent.
static bool tx_frame(const uint8_t* b, size_t n) {
  if ((size_t)Serial1.availableForWrite() < n) {
    g_tx_stuck++;
    bus_reopen();
    return false;
  }
  Serial1.write(b, n);
  return true;
}
int bus_stuck() { return (int)((g_tx_stuck & 0xFFFF) << 16 | (g_lock_lost & 0xFFFF)); }

// Drain what is waiting, bounded. The unbounded `while (Serial1.available()) Serial1.read();` spun forever when a
// servo kept talking (our left hip servo, 2026-10-04 15:3x-15:46: the whole bus and every RPC went quiet, even
// bus_baud, because the MCU's one RPC thread never left the loop). Returns the bytes dropped (g_junk counts them).
static uint32_t g_junk = 0;
static int bus_drain() {
  int n = 0;
  uint32_t t0 = micros();
  while (Serial1.available() && n < 512 && (uint32_t)(micros() - t0) < 2000u) { Serial1.read(); n++; }
  g_junk += n;
  return n;
}
int bus_junk() { return (int)g_junk; }

// Wait for a packet to leave, bounded. Serial1.flush() waits for transmit-complete with no limit; a UART left in
// an error state by a hot-plug glitch would hold the RPC thread (and bus_mtx) forever, which is what the wedges
// at 15:53-16:02 looked like: every RPC dead, bus_baud included, with the drain already bounded. The bytes take
// 10 bits each at the bus baud; a reply cannot start before the servo's return delay anyway.
static void tx_wait(size_t n) {
  uint32_t us = (uint32_t)((uint64_t)n * 10u * 1000000u / (uint32_t)(g_baud ? g_baud : 1000000)) + 30u;
  delayMicroseconds(us);
}

// Returns 1 when the bus was opened with the mutex held, 2 when it was opened while another call still held it
// (that call is stuck inside Serial1 and reopening the port is the only thing that can free it), never 0.
int bus_begin(int baud) {
  bool got = bus_lock();
  if (!got) g_lock_lost++;
  if (g_baud) Serial1.end();
  Serial1.begin((unsigned long)baud);
  g_baud = baud;
  if (got) k_mutex_unlock(&bus_mtx);
  return got ? 1 : 2;
}

// Sends tx, collects everything that comes back within wait_ms (echo included). Returns byte count.
int bus_send(std::vector<uint8_t> tx, int wait_ms) {
  if (!g_baud) return -1;
  if (wait_ms < 1) wait_ms = 1; if (wait_ms > 200) wait_ms = 200;
  if (!bus_lock()) { g_lock_lost++; return -2; }
  bus_drain();
  if (!tx_frame(tx.data(), tx.size())) { k_mutex_unlock(&bus_mtx); return -3; }
  tx_wait(tx.size());
  g_rxn = 0;
  uint32_t t0 = millis();
  while ((uint32_t)(millis() - t0) < (uint32_t)wait_ms) {
    while (Serial1.available() && g_rxn < (int)sizeof g_rx) g_rx[g_rxn++] = (uint8_t)Serial1.read();
  }
  int n = g_rxn;
  k_mutex_unlock(&bus_mtx);
  return n;
}

int bus_rx(int i) { return (i >= 0 && i < g_rxn) ? (int)g_rx[i] : -1; }
int bus_baud() { return g_baud; }

std::vector<uint8_t> bus_batch(std::vector<uint8_t> frames, int wait_us) {
  std::vector<uint8_t> out;
  if (!g_baud) return out;
  if (wait_us < 100) wait_us = 100; if (wait_us > 20000) wait_us = 20000;
  if (!bus_lock()) { g_lock_lost++; return out; }   // empty: the daemon reads that as a closed bus and reopens it
  out.reserve(frames.size() + 64);                  // no realloc while bytes are arriving at 10 us apart
  size_t k = 0;
  while (k + 5 <= frames.size()) {
    int expect = frames[k];
    size_t plen = 4 + (size_t)frames[k + 4];          // FF FF id len ... : len counts inst+params+chk
    if (frames[k + 1] != 0xFF || frames[k + 2] != 0xFF || k + 1 + plen > frames.size()) break;
    bus_drain();
    if (!tx_frame(&frames[k + 1], plen)) break;
    tx_wait(plen);
    size_t at = out.size();
    out.push_back(0);
    int n = 0;
    uint32_t t0 = micros();
    while (n < expect && n < 250 && (uint32_t)(micros() - t0) < (uint32_t)wait_us) {
      while (Serial1.available() && n < 250) { out.push_back((uint8_t)Serial1.read()); n++; }
    }
    out[at] = (uint8_t)n;
    k += 1 + plen;
  }
  k_mutex_unlock(&bus_mtx);
  return out;
}

// ---- MPU-6050 on I2C: which way is up (we soldered one on 2026-10-04 22:18) ----------------------------
// the robot had no inertial sensor, so the walking policy took its gyro and gravity from a simulated duck and could
// step but not balance. The part is a GY-521 at address 0x68 (AD0 to GND).
//
// WHICH BUS IT IS ON IS MEASURED, NEVER ASSUMED. we had no Qwiic cable, so it went onto the header:
// SCL = D21 = PB10, SDA = D20 = PB11. That is a DIFFERENT bus from the Qwiic socket. Read off the official
// core's own variant overlay (arduino/ArduinoCore-zephyr, variants/arduino_uno_q_stm32u585xx, fetched
// 2026-10-04): `zephyr,user` declares `i2cs = <&i2c2>, <&i2c4>, <&i2c3>`, and libraries/Wire/Wire.h names
// them in that order, so:
//
//   Wire  = i2c2   the header pins, D20 PB11 (SDA) and D21 PB10 (SCL). The overlay's own comments say
//                  "D20 - PB11" and "D21 - PB10", which is where the sensor is now.
//   Wire1 = i2c4   the Qwiic socket, i2c4_scl_pd12 and i2c4_sda_pd13
//   Wire2 = i2c3   i2c3_scl_pc0 and i2c3_sda_pc1
//
// i2c2 carries `zephyr,deferred-init` in that overlay, so it is not brought up until something calls begin().
// That is what imu_wire_begin does, and it is why a scan must begin a bus before scanning it.
//
// Every call here tries EVERY declared bus and reports which one answered, because a wire moved from the
// header to the Qwiic socket must not turn into a sensor that silently stopped existing.
//
//   imu_scan()                  -> [bus, addr, ...] for 0x68/0x69 only; imu_scan_all() sweeps 0x08..0x77
//   imu_begin(addr, dlpf, div)  -> [ok, bus, who_am_i, pwr, cfg, gyro_cfg, accel_cfg, smplrt] read BACK
//   imu_read()                  -> [n, 14 bytes] ax ay az temp gx gy gz, big-endian int16 each, or [0]
//   imu_stats()                 -> [ok lo, ok hi, err lo, err hi, addr, began, bus]
//
// Scales are fixed here and stated once: gyro +/-500 dps = 65.5 LSB per deg/s, accel +/-4 g = 8192 LSB per g.
// The Linux side owns every conversion, the same way it owns the servo register map.
//
// NOTHING ON THIS MCU MAY WAIT FOR EVER - and checking Wire's return value is NOT enough to promise that.
// This core's TwoWire calls Zephyr i2c_write/i2c_read straight through (libraries/Wire/Wire.cpp:117,138),
// and the STM32 driver waits on its completion semaphore with K_FOREVER. A sensor that holds SDA down, or
// an interrupt that never arrives, blocks the CALLER for ever, and before 2026-10-05 00:4x that caller was
// the RPC thread: /api/health went to hz 0 with 98 timeouts while bus_batch sat unanswered behind one
// stuck I2C read. Every transaction below therefore runs on imu_thread and NOWHERE else. The four RPC
// handlers touch a snapshot and a few flags, so the worst a wedged I2C bus can now cost is the IMU.
#define IMU_PWR1 0x6B
#define IMU_CFG 0x1A
#define IMU_SMPLRT 0x19
#define IMU_GYRO_CFG 0x1B
#define IMU_ACCEL_CFG 0x1C
#define IMU_BURST 0x3B
#define IMU_WHOAMI 0x75

// The buses this build has, in the order Wire.h declares them. If a future variant drops one, the compile
// fails here and loudly, which is the right place for that to happen.
static TwoWire* const IMU_BUSES[] = {&Wire, &Wire1, &Wire2};
#define IMU_NBUS ((int)(sizeof IMU_BUSES / sizeof IMU_BUSES[0]))
static bool imu_bus_up[IMU_NBUS];
static uint8_t imu_addr = 0;
static int imu_bus = -1;              // which bus answered; -1 = none has
static bool imu_began = false;
static uint32_t imu_ok_n = 0, imu_err_n = 0;

static TwoWire* imu_wire_begin(int b) {
  if (b < 0 || b >= IMU_NBUS) return nullptr;
  if (!imu_bus_up[b]) {
    IMU_BUSES[b]->begin();          // i2c2 is deferred-init in the variant: nothing works before this
    IMU_BUSES[b]->setClock(400000);
    imu_bus_up[b] = true;
  }
  return IMU_BUSES[b];
}

// -1 when the chip did not answer, so a caller can never mistake a dead bus for a register that reads 0
static int imu_reg(int b, uint8_t addr, uint8_t reg) {
  TwoWire* w = imu_wire_begin(b);
  if (!w) return -1;
  w->beginTransmission(addr);
  w->write(reg);
  if (w->endTransmission(false) != 0) return -1;
  if (w->requestFrom((int)addr, 1) != 1) return -1;
  return w->read();
}

static bool imu_write(int b, uint8_t addr, uint8_t reg, uint8_t val) {
  TwoWire* w = imu_wire_begin(b);
  if (!w) return false;
  w->beginTransmission(addr);
  w->write(reg);
  w->write(val);
  return w->endTransmission(true) == 0;
}

static bool imu_acks(int b, uint8_t addr) {
  TwoWire* w = imu_wire_begin(b);
  if (!w) return false;
  w->beginTransmission(addr);
  return w->endTransmission(true) == 0;
}

// [bus, addr, bus, addr, ...] so one call answers "is it wired to the header or the Qwiic socket"
static std::vector<uint8_t> imu_scan_i2c(bool full) {
  std::vector<uint8_t> found;
  for (int b = 0; b < IMU_NBUS; b++) {
    // 0x68 and 0x69 are the MPU-6050's only two addresses. A full 0x08..0x77 sweep is 112 probes a bus,
    // each one a timeout when nothing is there, and polling it cost the servo bus on 2026-10-05.
    for (uint8_t a = full ? 0x08 : 0x68; a <= (full ? 0x77 : 0x69); a++) {
      if (imu_acks(b, a)) {
        found.push_back((uint8_t)b);
        found.push_back(a);
      }
    }
  }
  return found;
}

// Tries every bus until one carries an MPU-6050 at `addr`, then configures it there. Everything is READ
// BACK from the chip: a write that did not land must not look like a configured sensor.
static std::vector<int> imu_begin_i2c(int addr, int dlpf, int div) {
  std::vector<int> out;
  uint8_t a = (uint8_t)(addr ? addr : 0x68);
  if (dlpf < 0 || dlpf > 6) dlpf = 3;    // 44 Hz accel / 42 Hz gyro, 4.9 ms group delay, for a 50 Hz loop
  if (div < 0 || div > 255) div = 4;     // 1 kHz / (1 + 4) = 200 Hz sample rate
  imu_began = false;
  imu_addr = 0;
  imu_bus = -1;
  int last_who = -1;
  for (int b = 0; b < IMU_NBUS; b++) {
    if (!imu_acks(b, a)) continue;                 // nothing at that address on this bus: next bus
    if (!imu_write(b, a, IMU_PWR1, 0x80)) continue;  // reset
    delay(100);
    if (!imu_write(b, a, IMU_PWR1, 0x01)) continue;  // wake, clock from the X gyro
    delay(10);
    imu_write(b, a, IMU_CFG, (uint8_t)dlpf);
    imu_write(b, a, IMU_SMPLRT, (uint8_t)div);
    imu_write(b, a, IMU_GYRO_CFG, 0x08);           // +/- 500 dps
    imu_write(b, a, IMU_ACCEL_CFG, 0x08);          // +/- 4 g
    delay(10);
    int who = imu_reg(b, a, IMU_WHOAMI), pwr = imu_reg(b, a, IMU_PWR1), cfg = imu_reg(b, a, IMU_CFG);
    int gy = imu_reg(b, a, IMU_GYRO_CFG), ac = imu_reg(b, a, IMU_ACCEL_CFG), sr = imu_reg(b, a, IMU_SMPLRT);
    last_who = who;
    if (who == 0x68 && pwr >= 0 && (pwr & 0x40) == 0 && gy == 0x08 && ac == 0x08) {
      imu_began = true;
      imu_addr = a;
      imu_bus = b;
      out.push_back(1); out.push_back(b); out.push_back(who); out.push_back(pwr);
      out.push_back(cfg); out.push_back(gy); out.push_back(ac); out.push_back(sr);
      return out;
    }
  }
  // nothing usable anywhere: say so with the last WHO_AM_I seen, never with a bus number
  out.push_back(0); out.push_back(-1); out.push_back(last_who);
  out.push_back(-1); out.push_back(-1); out.push_back(-1); out.push_back(-1); out.push_back(-1);
  return out;
}

static std::vector<uint8_t> imu_read_i2c() {
  std::vector<uint8_t> out;
  if (!imu_began || imu_bus < 0) { out.push_back(0); return out; }
  TwoWire* w = imu_wire_begin(imu_bus);
  if (!w) { out.push_back(0); return out; }
  w->beginTransmission(imu_addr);
  w->write(IMU_BURST);
  if (w->endTransmission(false) != 0) { imu_err_n++; out.push_back(0); return out; }
  int n = w->requestFrom((int)imu_addr, 14);
  if (n != 14) { imu_err_n++; out.push_back(0); return out; }
  out.push_back(14);
  for (int i = 0; i < 14; i++) out.push_back((uint8_t)w->read());
  imu_ok_n++;
  return out;
}

// ---- the sampler thread: the only code in this sketch allowed to touch I2C --------------------------
K_THREAD_STACK_DEFINE(imu_stack, 2048);
static struct k_thread imu_thread;
static volatile uint32_t imu_seq = 0;           // seqlock: odd while writing, even when the snapshot is whole
static uint8_t imu_snap[14];
static volatile uint32_t imu_snap_ms = 0;
static volatile uint32_t imu_loops = 0;         // proves the thread is alive; frozen = it is stuck in I2C
static volatile int imu_want_begin = 0, imu_want_scan = 0, imu_scan_full = 0;
static volatile int imu_req_addr = 0x68, imu_req_dlpf = 3, imu_req_div = 4;
static int imu_begin_out[8] = {0, -1, -1, -1, -1, -1, -1, -1};
static uint8_t imu_scan_out[32];
static volatile int imu_scan_n = 0;
static volatile uint32_t imu_begin_seq = 0, imu_scan_seq = 0;
static volatile uint32_t imu_miss = 0;          // consecutive failed reads
#define IMU_MISS_GIVE_UP 10                     // after this the thread stops touching the bus until a begin
#define IMU_PERIOD_MS 20                        // 50 Hz, the policy's own rate: the I2C runs on this
                                                // thread and rides out on poll_get, so it costs no RPCs
#define IMU_STALE_MS 500                        // a snapshot older than this is not a reading

static void imu_loop(void*, void*, void*) {
  while (true) {
    imu_loops++;
    if (imu_want_scan) {
      std::vector<uint8_t> f = imu_scan_i2c(imu_scan_full != 0);
      int n = (int)f.size(); if (n > (int)sizeof imu_scan_out) n = (int)sizeof imu_scan_out;
      for (int i = 0; i < n; i++) imu_scan_out[i] = f[i];
      imu_scan_n = n;
      imu_scan_seq++;
      imu_want_scan = 0;
    }
    if (imu_want_begin) {
      std::vector<int> r = imu_begin_i2c(imu_req_addr, imu_req_dlpf, imu_req_div);
      for (int i = 0; i < 8 && i < (int)r.size(); i++) imu_begin_out[i] = r[i];
      imu_miss = 0;
      imu_begin_seq++;
      imu_want_begin = 0;
    }
    if (imu_began && imu_miss < IMU_MISS_GIVE_UP) {
      std::vector<uint8_t> r = imu_read_i2c();
      if (r.size() == 15 && r[0] == 14) {
        imu_seq++;                        // odd: a reader that sees this retries rather than tearing
        __sync_synchronize();
        for (int i = 0; i < 14; i++) imu_snap[i] = r[i + 1];
        __sync_synchronize();
        imu_seq++;                        // even again: whole
        imu_snap_ms = millis();
        imu_miss = 0;
      } else {
        imu_miss++;
      }
    }
    k_msleep(IMU_PERIOD_MS);
  }
}

// Wait for the sampler to answer, without ever blocking on it. A wedged I2C bus means the sampler never
// comes back, and then this returns the honest "not yet" instead of taking the RPC thread down with it.
static bool imu_wait(volatile uint32_t* seq, uint32_t was, int ms) {
  for (int i = 0; i < ms; i += 10) {
    if (*seq != was) return true;
    k_msleep(10);
  }
  return false;
}

// ---- the four RPC faces: snapshots and flags, never a bus transaction -------------------------------
static std::vector<uint8_t> imu_scan_req(bool full) {
  uint32_t was = imu_scan_seq;
  imu_scan_full = full ? 1 : 0;
  imu_want_scan = 1;
  std::vector<uint8_t> out;
  // This sleeps the RPC thread, so a scan stalls bus_batch for as long as it waits. 2.5 s is a deliberate,
  // rare diagnostic; the daemon's own imu_scan timeout is 10 s, so it hears the honest empty answer.
  if (!imu_wait(&imu_scan_seq, was, 2500)) return out;      // empty = the sampler did not answer in time
  for (int i = 0; i < imu_scan_n; i++) out.push_back(imu_scan_out[i]);
  return out;
}
// Two names rather than an argument, so the daemon's existing zero-argument call keeps working and the
// expensive sweep has to be asked for on purpose.
std::vector<uint8_t> imu_scan() { return imu_scan_req(false); }
std::vector<uint8_t> imu_scan_all() { return imu_scan_req(true); }

std::vector<int> imu_begin(int addr, int dlpf, int div) {
  uint32_t was = imu_begin_seq;
  imu_req_addr = addr ? addr : 0x68;
  imu_req_dlpf = dlpf;
  imu_req_div = div;
  imu_want_begin = 1;
  std::vector<int> out;
  // 800 ms and not longer: the daemon gives this call 900 ms (MX_TIMEOUT), and an answer it never hears
  // leaves a call unanswered on the bridge, which is what a backed-up link looks like from the outside.
  if (!imu_wait(&imu_begin_seq, was, 800)) {
    // -2 is not a WHO_AM_I: it says the I2C bus did not come back, which is a different fault from a
    // chip that answered wrongly, and a caller that cannot tell them apart will chase the wrong wire.
    out.push_back(0); out.push_back(-1); out.push_back(-2);
    out.push_back(-1); out.push_back(-1); out.push_back(-1); out.push_back(-1); out.push_back(-1);
    return out;
  }
  for (int i = 0; i < 8; i++) out.push_back(imu_begin_out[i]);
  return out;
}

// Read the snapshot without locking: a mutex here could be held by a sampler stuck inside I2C, and then
// the RPC thread would wait on it - exactly the failure this whole arrangement exists to prevent.
static bool imu_snapshot(uint8_t out[14], uint32_t* age_ms) {
  for (int t = 0; t < 8; t++) {
    uint32_t s1 = imu_seq;
    if (s1 & 1) { k_yield(); continue; }     // odd: the sampler is mid-write, so this copy would tear
    __sync_synchronize();
    for (int i = 0; i < 14; i++) out[i] = imu_snap[i];
    __sync_synchronize();
    if (imu_seq == s1) {
      *age_ms = millis() - imu_snap_ms;
      return imu_snap_ms != 0;
    }
  }
  return false;
}
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
void loop() {
  if (!g_baud) { delay(5); return; }
  k_mutex_lock(&p_mtx, K_FOREVER);
  bool any = p_n > 0 || p_on;
  k_mutex_unlock(&p_mtx);
  if (!any) { delay(5); return; }
  sweep();
  // one tick off the bus per sweep. The sweep holds no mutex here, but it ran back to back with nothing but a
  // k_yield, which only reaches threads of equal or higher priority; a measured poll_get waited up to 430 ms.
  k_msleep(1);
}

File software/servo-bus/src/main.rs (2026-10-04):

//! servo-bus: the Rust daemon that owns the servo bus, running on the Uno Q itself.
//!
//! It speaks the RouterBridge msgpack protocol directly on /var/run/arduino-router.sock, drives
//! the MCU app servo-bus-bridge over the bus_batch fast path, and serves the live control page
//! on :8938 with WebSocket state at about 50 Hz. From a computer over USB, reach it with
//! `adb forward tcp:8938 tcp:8938`.
//!
//! Build (Mac, cross): cargo zigbuild --release --target aarch64-unknown-linux-gnu
//! Run (board):        ./servo-bus --port 8938 --ids 1,2,3

mod bridge;
mod bus;
mod feetech;
mod http;
mod io;
mod json;
mod limits;
mod msgpack;
mod policy;
mod rawgate;
mod registry;
mod roster;
mod setid;

use std::sync::mpsc;
use std::sync::{Arc, Mutex};

fn arg(name: &str, default: &str) -> String {
    let a: Vec<String> = std::env::args().collect();
    a.iter().position(|x| x == name).and_then(|i| a.get(i + 1).cloned()).unwrap_or_else(|| default.to_string())
}

fn flag(name: &str) -> bool {
    std::env::args().any(|x| x == name)
}

fn main() {
    let port: u16 = arg("--port", "8938").parse().unwrap_or(8938);
    let sock = arg("--sock", bridge::DEFAULT_SOCK);
    // motion set for the engineer view's wave and sliders; empty = no motion at all (the customer default)
    let ids: Vec<u8> = arg("--ids", "").split(',').filter_map(|x| x.trim().parse().ok()).collect();
    let reg_path = arg("--registry", "servo-ids.json");
    let app = arg("--mcu-app", "user:servo-bus-bridge");
    let tz: i64 = arg("--tz", "8").parse().unwrap_or(8);
    let fake = flag("--fake");
    if flag("--probe") {
        // one ping chunk per call, timed: the bus_batch path alone, no roster, no page
        let n: usize = arg("--probe", "100").parse().unwrap_or(100);
        let tmo: u64 = arg("--timeout-ms", "1000").parse().unwrap_or(1000);
        let mut io = io::RouterIo { bridge: bridge::Bridge::new(&sock), app };
        println!("begin {:?}", io::Io::begin(&mut io));
        let t0 = std::time::Instant::now();
        for k in 0..n {
            let base = ((k * 8) % 256).min(246) as u8;
            let frames: Vec<Vec<u8>> = (base..base + 8).map(feetech::ping).collect();
            let ex: Vec<usize> = frames.iter().map(|f| f.len() + 6).collect();
            let t = std::time::Instant::now();
            let r = io::Io::batch(&mut io, &frames, &ex, 1000, std::time::Duration::from_millis(tmo));
            let ms = t.elapsed().as_secs_f64() * 1000.0;
            if r.is_err() || k < 5 || ms > 60.0 {
                println!("call {k} ids {base}.. {:.1} ms {:?}", ms, r.as_ref().map(|v| v.iter().map(|x| x.len()).collect::<Vec<_>>()));
            }
            if r.is_err() {
                std::process::exit(1);
            }
        }
        println!("ok {n} calls in {:.1} s", t0.elapsed().as_secs_f64());
        return;
    }
    let registry = registry::Registry::load(&reg_path);
    let (tx, rx) = mpsc::channel::<bus::Cmd>();
    let mut shared = bus::Shared::new(ids.clone(), registry);
    shared.roster.log_path = Some(arg("--events", &if reg_path.ends_with("-ids.json") { reg_path.replace("-ids.json", "-events.jsonl") } else { reg_path.replace(".json", "-events.jsonl") }));
    let lim_path = arg("--limits", &if reg_path.ends_with("-ids.json") { reg_path.replace("-ids.json", "-limits.json") } else { reg_path.replace(".json", "-limits.json") });
    shared.limits = limits::Limits::load(&lim_path);
    shared.tz_h = tz;
    shared.fake = fake;
    let sh = Arc::new(Mutex::new(shared));
    let io: Box<dyn io::Io> = if fake {
        // a demo bench: the adapter, two right-leg servos and two factory-ID servos plugged in together
        let mut b = io::FakeBus::new(&[(100, 2980), (13, 240), (14, 682)]);
        b.servos.push(io::FakeServo::new(1, 250));
        b.servos.push(io::FakeServo::new(1, 700));
        Box::new(b)
    } else {
        Box::new(io::RouterIo { bridge: bridge::Bridge::new(&sock), app })
    };
    {
        let sh = sh.clone();
        let mx = Some(arg("--matrix-frame", "")).filter(|p| !p.is_empty());
        policy::POLICY.lock().unwrap().dir = Some(arg("--policy-dir", "")).filter(|p| !p.is_empty());
        std::thread::spawn(move || bus::run(io, sh, rx, mx));
    }
    let listener = match std::net::TcpListener::bind(("0.0.0.0", port)) {
        Ok(l) => l,
        Err(e) => {
            eprintln!("bind :{port}: {e}");
            std::process::exit(1);
        }
    };
    println!("servo-bus ready on :{port} motion ids {:?} registry {reg_path}{}", ids, if fake { " FAKE BUS" } else { "" });
    use std::io::Write;
    std::io::stdout().flush().ok();
    http::serve(listener, sh, tx);
}

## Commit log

2026-10-04 Electronics, firmware and control software for a 15-servo walking robot
    The UNO Q hat and a small body IMU breakout as KiCad projects with gerbers and
    BOMs, the Arduino sketch that runs the servo chain, and the Rust daemon that
    owns the bus and serves a live control page at 50 Hz.
    Software and firmware are Apache-2.0. The board designs are CC BY-SA 4.0,
    because the camera routing is copied from Arduino's UNO Media Carrier.
    [bom.csv, servo-ids.json, trunk_imu.kicad_pcb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]
2026-10-10 hat rev C: boost to UNO Q VIN, EN divider fix, checks and docs
    Rev C of the UNO Q head hat (foreman/microduck-assembly.60, 2026-10-10):
    - TPS61088 boost (U10) makes 11.86 V from the 2S pack into the UNO Q VIN
    (JMEDIA 57/59); the hat no longer back-feeds the UNO Q 5 V.
    - U10 EN now sits on a 100k/100k divider from VBAT_B. Earlier Rev C builds
    tied EN to VCC, the output of an LDO that EN itself enables, so the boost
    would never have started. DRC and ERC could not see it.
    - Interrupts on 3.3 V MCU pins, D40 isolates the servo pull-ups.
    - kicad_dru no longer carries a 0.09 mm clearance rule: it replaced the
    0.127 mm zone clearance and filled GND inside the JMEDIA mask openings.
    Checks: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
    [bom.csv, unoq_hat.kicad_pcb, unoq_hat.kicad_sch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]
2026-10-10 hat Rev C build #10: 6-pin J6 (6 A), order sheet for 2026-10-11
    - J6 is now S6B-PH-SM4-TB (C265405), three contacts per pole: 6 A vs 4.72 A worst case
    - VBAT_IN pour widened for J6; KiCad DRC 0/0/0 (board and JLC rules), ERC 0/0, 75/75 nets
    - fab: gerbers.zip, bom.csv (55 lines), cpl.csv (95 parts); BOM in stock for 5 boards at 14:53Z
    - ce-fabmcp pcb_drc on build #10: In1/In2 PASS, F/B approximation FAIL explained
    - docs/PCB-ORDER-LEIF-2026-10-11.md: one-page order sheet with J6-to-XT30 pigtail kit line
    Signed: foreman/microduck-assembly.60
    [bom.csv, unoq_hat.kicad_pcb, unoq_hat.kicad_sch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]
2026-10-10 order sheet: download links for gerbers/bom/cpl
    Signed: foreman/microduck-assembly
2026-10-10 Rev C BOM: stock rechecked 2026-10-10T21:03Z, 51 lines, 0 short at JLC
